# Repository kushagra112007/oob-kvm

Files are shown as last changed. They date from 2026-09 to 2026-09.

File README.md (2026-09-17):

# Zero-Cloud Out-of-Band (OOB) Laptop KVM & Power Node

> **45-Second Demo Video:**

https://github.com/user-attachments/assets/9a236c90-bcca-4cf3-b19a-8e18de248222



An ultra-low-cost (~$6.90 USD) hardware out-of-band management solution designed for headless laptop servers lacking Wake-on-LAN support. Features non-blocking mechanical power button actuation, zero-cloud REST API control, multi-tier SSH snippet integration, offline IR air-gapped fallback, and pre-boot optical KVM telemetry.

---

##  Key Features

* **Physical Button Actuation:** Overrides ACPI S5 and Wake-on-LAN failure states using a calibrated SG90 micro-servo.
* **Smooth Sweep C++ Engine:** Custom pulse-width calibration (500–2400µs) with non-blocking `yield()` loops prevents Watchdog (WDT) resets, gear stripping, and base lift.
* **REST API & IR Control:** Network endpoints for `/wake`, `/power`, and `/panic`, backed by an offline IR remote module for local air-gapped overrides.
* **Pre-Boot Optical KVM:** Repurposed Android camera bridge running **IP Webcam** to capture raw POST/BIOS screen display output before OS GPU drivers load.
* **Multi-Tier Secure Access:** Zero-exposure networking routed globally over WireGuard / Tailscale mesh tunnels (CGNAT bypass).
* **Automated WAN Failover:** Edge gateway logic on the phone automatically switches to a 4G LTE hotspot during home broadband outages (~20s recovery).

---

## Hardware Architecture & Pre-Boot Telemetry

Most laptop motherboards disable HDMI, DisplayPort, and Type-C outputs during initial execution (POST, BIOS/UEFI, early kernel boot), enabling external ports only after OS display drivers load.

To maintain continuous visual monitoring before the OS boots, an external smartphone camera running **IP Webcam** pointed at the primary laptop panel acts as an out-of-band optical capture bridge.

### Bill of Materials (BOM)

| Component | Quantity | Cost (USD) | Function / Notes |
| :--- | :---: | :---: | :--- |
| **NodeMCU ESP8266** | 1 | $4.20 | REST Web Server & Actuator Controller |
| **SG90 Micro Servo** | 1 | $1.14 | Physical power button actuator |
| **IR Remote + Receiver Module** | 1 | $0.84 | Offline air-gapped manual fallback override |
| **Micro-USB Power Cable** | 1 | $0.60 | Power delivery to NodeMCU |
| **Jumper Wires** | Pack | $0.12 | Signal & GPIO power routing |
| **Asus ZenFone (2018)** | 1 | $0.00 | E-waste recovery: Optical POST/BIOS camera bridge & SSH Gateway Bridge |
| **Tenda Router** | 1 | $0.00 | E-waste recovery: Local subnet AP / MAC-to-IP reservation node |
| **Wooden Platter Mount** | 1 | $0.00 | Repurposed scrap mount base |
| **3D Printed Arm & Bracket** | 1 | $0.00 | Custom STL lever extension (College lab perk) |
| **TOTAL** | | **~$6.90** | **Complete OOB-KVM Node** |

---

###  Execution Steps

1. **Trigger Delivery:** Initiate an SSH snippet or cURL payload from your remote client (OnePlus / Termius) over the encrypted Tailscale mesh tunnel to the gateway phone (`100.x.y.z:8022`).
2. **Local Payload Dispatch:** The gateway phone receives the ingress packet and executes an internal shell alias that issues an HTTP GET request across the isolated Tenda subnet (`192.168.0.x`) targeting the NodeMCU endpoint.
3. **Hardware Switch Actuation:** The NodeMCU processes the REST call (`/wake`, `/power`, or `/panic`), sweeps the SG90 micro-servo to depress the physical ACPI power button, and automatically resets to its neutral 180° resting state.
4. **Visual Telemetry Verification:** If OS-level remote access (SSH/RDP) fails or hangs, stream the IP Webcam feed to inspect live pre-boot POST output, BIOS menus, or kernel panic crash logs.
---

##  Network Topology & Control Workflow

The setup isolates management traffic on a dedicated sub-router subnet to guarantee static routing and prevent IP drift across power cycles.

### Static Subnet Reservations (Tenda AP - `192.168.1.x`)
* **Target Server Host (`cachyos-x86_64`):** Reserved at `192.168.1.100`
* **Gateway Phone Bridge:** Reserved at `192.168.1.101`
* **NodeMCU ESP8266 Actuator:** Reserved at `192.168.1.102` (Static DHCP Lease)
---

| Layer | Transport Channel | Range / Context | Operating Requirements | Failure Mitigation Target |
| :--- | :--- | :--- | :--- | :--- |
| **Primary (Global OOB)** | Tailscale WireGuard + SSH | Global (Cellular / 5G) | Cellular Data + Gateway Phone Active | Worldwide server recovery & optical screen capture |
| **Secondary (Local LAN)** | HTTP REST API over Local Wi-Fi | Local Subnet Radius | Local Tenda AP Active | Bypasses WAN internet outages or Tailscale relay downtime |
| **Tertiary (Air-Gap)** | 38kHz Infrared Signal (GPIO D2) | Physical Desk Radius (Line-of-Sight) | 5V Power to NodeMCU Only | Functions when Wi-Fi routers, SSH bridges, and local subnets fail entirely |

```text
[ Remote Client (Mobile / 5G) ]
       │
       ▼ (Encrypted WireGuard Mesh via Tailscale)
[ Gateway Phone Bridge (100.x.y.z:8022) ] ──> IP Webcam Stream / Video Capture
       │
       ▼ (Local HTTP Payload / cURL Script across Tenda Subnet)
[ NodeMCU Actuator (192.168.1.102) ]
       │
       ▼ (Sweeps SG90 Servo to depress power key)
[ Target Server (`cachyos-x86_64` @ 192.168.1.100) ]
---

## 🔧 REST API Endpoints

```text
GET /wake     -> Triggers 1.5-second display/sleep toggle press
GET /power    -> Triggers 5.0-second standard power-on hold
GET /panic    -> Triggers 15.0-second hard kernel freeze power cycle
GET /release  -> Resets servo back to 0° rest position
```

---

## License & Community

Featured in the top 10 projects on r/techsupportmacgyver (July 2026).  
Distributed under the MIT License.

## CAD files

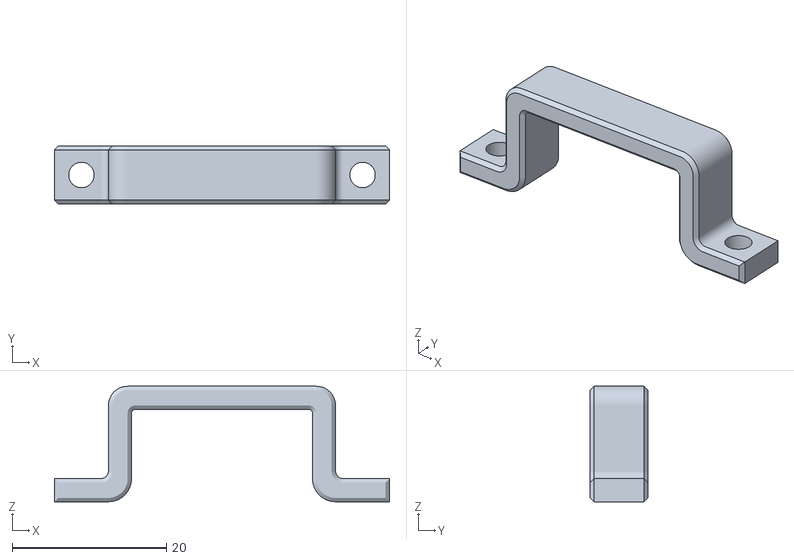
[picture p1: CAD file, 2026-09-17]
cad/servo_arm_-_clamp_sg90.stl
43.5 x 7.50 x 15.0

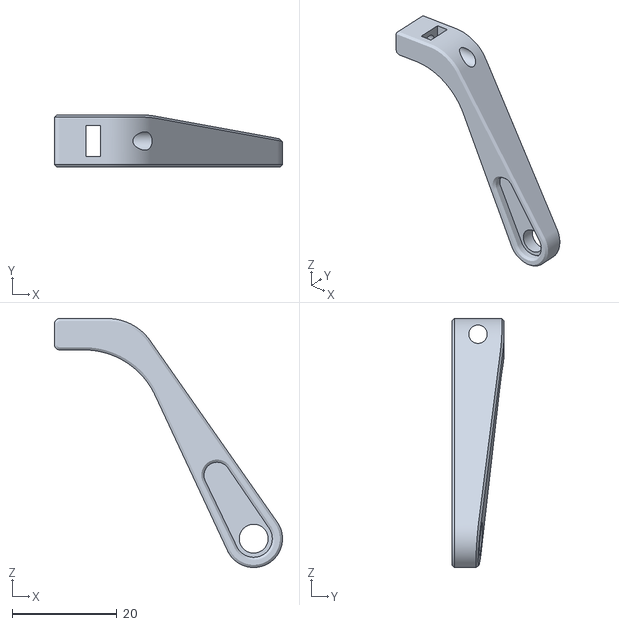
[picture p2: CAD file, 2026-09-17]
cad/servo_arm_-_arm_sg90.stl
43.5 x 10.0 x 47.5

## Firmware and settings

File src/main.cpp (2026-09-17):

#include <ESP8266WiFi.h>
#include <ESP8266WebServer.h>
#include <Servo.h>
#include <IRremoteESP8266.h>
#include <IRrecv.h>
#include <IRutils.h>

// --- WI-FI CREDENTIALS ---
// REPLACE THESE PLACEHOLDERS BEFORE COMPILING
const char* ssid     = "YOUR_WIFI_SSID";
const char* password = "YOUR_WIFI_PASSWORD";

// --- PIN & PULSE DEFINITIONS ---
const int SERVO_PIN = D4; // Yellow/Orange signal wire on D4
const int IR_PIN    = D2; // IR Sensor signal wire on D2

// SG90 Extended Pulse Bounds (Microseconds)
const int MIN_PULSE = 500;  // Forces true 0 deg reach
const int MAX_PULSE = 2400; // Forces true 180 deg reach

// --- IR REMOTE CODES ---
const uint32_t BTN_DOWN = 0xFF4AB5; // DOWN -> 5-Second Power Tap
const uint32_t BTN_UP   = 0xFF18E7; // UP   -> Manual Emergency Release to 180 deg

// --- SERVO ANGLES & TIMINGS ---
const int ANGLE_UP   = 180; // Rest position (9 o'clock)
const int ANGLE_DOWN = 110; // Press position (6 o'clock onto power button)

const int WAKE_DURATION     = 1500;  // 1.5 seconds
const int POWER_ON_DURATION = 5000;  // 5 seconds
const int PANIC_DURATION    = 15000; // 15 seconds

Servo myServo;
IRrecv irrecv(IR_PIN);
decode_results results;
ESP8266WebServer server(80);

// Helper function to handle non-blocking button press with explicit pulse widths
void pressPowerButton(int durationMs, String label) {
  Serial.print("Executing: ");
  Serial.println(label);

  // Attach using explicit min/max pulse limits
  myServo.attach(SERVO_PIN, MIN_PULSE, MAX_PULSE);
  myServo.write(ANGLE_DOWN);
  
  unsigned long start = millis();
  while (millis() - start < durationMs) {
    server.handleClient(); // Keep server listening during holds
    yield();               // Keep Wi-Fi & Watchdog fed to prevent WDT resets
    delay(10);
  }

  myServo.write(ANGLE_UP);
  delay(400);              // Give motor physical time to reach 180 deg
  myServo.detach();        // Stop active PWM pulse to eliminate idle chatter/heat
  Serial.println("Action Complete: Servo returned to 180 deg and detached.");
}

// --- HTTP ROUTE HANDLERS ---
void handleRoot() {
  String html = "<html><head><title>OOB Power Node Control</title>";
  html += "<meta name='viewport' content='width=device-width, initial-scale=1'>";
  html += "<style>body{font-family:Arial,sans-serif; text-align:center; margin-top:40px; background:#121212; color:#eee;}";
  html += ".btn{display:inline-block; width:80%; max-width:300px; padding:15px; margin:10px; font-size:18px; color:white; border:none; border-radius:8px; text-decoration:none; cursor:pointer;}";
  html += ".wake{background-color:#2196F3;}";
  html += ".power{background-color:#4CAF50;}";
  html += ".panic{background-color:#f44336;}";
  html += ".release{background-color:#757575;}";
  html += "</style></head><body>";
  html += "<h2>Out-of-Band Power Control</h2>";
  html += "<p><a href='/wake'><button class='btn wake'>Wake Display (1.5s)</button></a></p>";
  html += "<p><a href='/power'><button class='btn power'>Power On (5s)</button></a></p>";
  html += "<p><a href='/panic'><button class='btn panic'>Kernel Panic Reset (15s)</button></a></p>";
  html += "<p><a href='/release'><button class='btn release'>Force Release (180 deg)</button></a></p>";
  html += "</body></html>";
  
  server.send(200, "text/html", html);
}

void handleWake() {
  server.send(200, "text/plain", "Triggering 1.5s Display Wake...");
  pressPowerButton(WAKE_DURATION, "1.5s Display Wake");
}

void handlePower() {
  server.send(200, "text/plain", "Triggering 5s Power On sequence...");
  pressPowerButton(POWER_ON_DURATION, "5s Power On");
}

void handlePanic() {
  server.send(200, "text/plain", "Triggering 15s Kernel Panic Cold Boot...");
  pressPowerButton(PANIC_DURATION, "15s Cold Boot");
}

void handleRelease() {
  myServo.attach(SERVO_PIN, MIN_PULSE, MAX_PULSE);
  myServo.write(ANGLE_UP);
  delay(400);
  myServo.detach();
  server.send(200, "text/plain", "Emergency Release: Moved back to 180 degrees.");
}

void setup() {
  Serial.begin(115200);
  delay(500);

  // Initial position alignment and release
  myServo.attach(SERVO_PIN, MIN_PULSE, MAX_PULSE);
  myServo.write(ANGLE_UP);
  delay(400);
  myServo.detach();

  // Start IR Receiver on D2
  irrecv.enableIRIn();

  // Connect to Wi-Fi
  WiFi.mode(WIFI_STA);
  WiFi.begin(ssid, password);
  Serial.print("\nConnecting to Wi-Fi");
  
  while (WiFi.status() != WL_CONNECTED) {
    delay(500);
    Serial.print(".");
  }
  
  Serial.println("\nConnected to Wi-Fi!");
  Serial.print("NodeMCU IP Address: http://");
  Serial.println(WiFi.localIP());

  // Web Server Routes
  server.on("/", handleRoot);
  server.on("/wake", handleWake);
  server.on("/power", handlePower);
  server.on("/panic", handlePanic);
  server.on("/release", handleRelease);

  server.begin();
  Serial.println("Web Server & IR Receiver Ready!");
}

void loop() {
  // Listen for Web HTTP requests
  server.handleClient();

  // Listen for IR Remote Signals
  if (irrecv.decode(&results)) {
    uint32_t code = results.value;

    if (code != 0xFFFFFFFF && code != 0x0) { 
      Serial.print("IR Received: 0x");
      Serial.println(code, HEX);

      if (code == BTN_DOWN) {
        pressPowerButton(POWER_ON_DURATION, "IR Remote 5s Press");
      } 
      else if (code == BTN_UP) {
        myServo.attach(SERVO_PIN, MIN_PULSE, MAX_PULSE);
        myServo.write(ANGLE_UP);
        delay(400);
        myServo.detach();
        Serial.println("IR Remote Action: Moved UP to 180 deg");
      }
    }
    
    irrecv.resume();
  }
}

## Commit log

2026-09-17 Revise README with updated features and BOM
    Updated hardware specifications, features, and execution steps. Revised cost estimates and added new components.
2026-09-17 Refactor servo angles and update HTTP responses
    Updated servo angles and HTTP response messages for better clarity and functionality.
2026-09-17 Add README.md for CAD files
